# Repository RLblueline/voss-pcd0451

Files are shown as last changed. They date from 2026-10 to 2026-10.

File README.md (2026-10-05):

# V.O.S.S. — PCD-0451

**Virtual Oversight & Supervision System.** A wall-mounted, Claude-powered home assistant
on a spring-balanced robot arm, with a deep, late-'70s HR-terminal head:
- **Moves:** the arm swivels, lifts and leans, like a desk lamp.
- **Eye:** an amber eye slides up and down a slot behind mechanical eyelids.
- **Sound:** she answers out loud through an intercom filter.
- **Paper:** she prints memos.

> Personal, non-commercial fan build in the style of Valve's Portal. Aperture Science
> belongs to Valve; V.O.S.S. and Dr. Harriet Voss are original fan characters. The
> department seal is an original design, not the Aperture logo.

| | | |
|---|---|---|
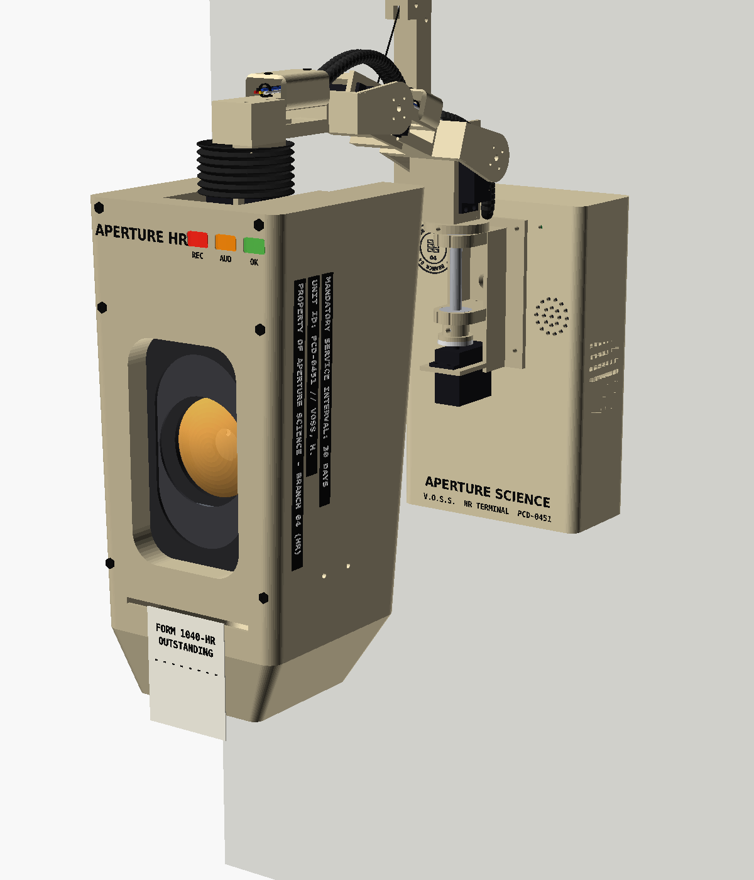
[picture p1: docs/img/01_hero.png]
Hero
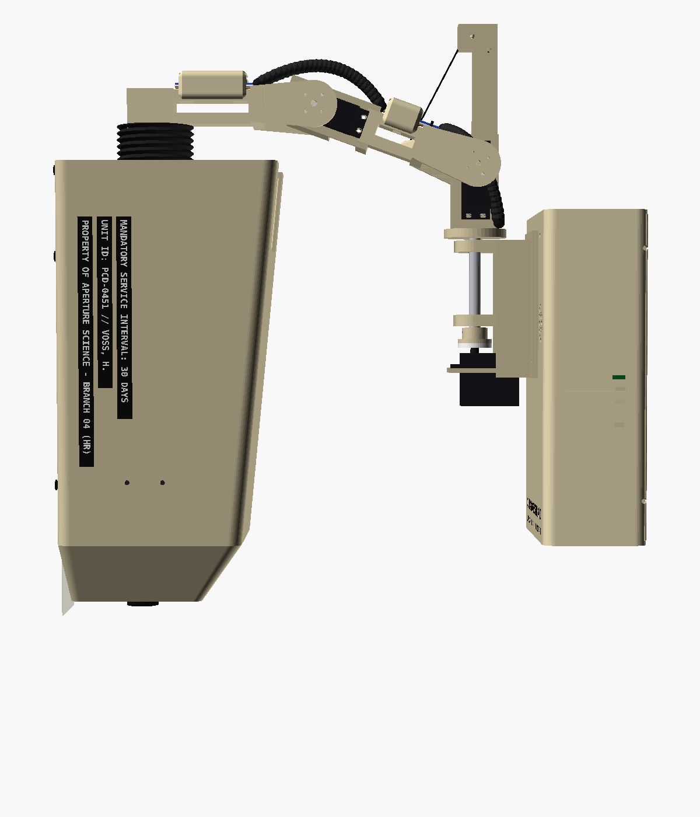
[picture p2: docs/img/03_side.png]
Side
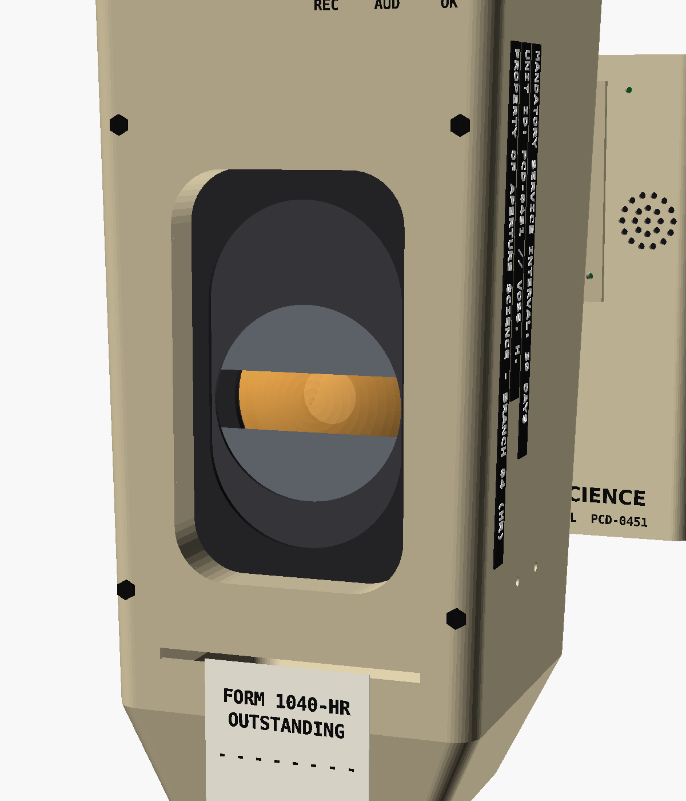
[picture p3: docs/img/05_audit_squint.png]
Audit squint
|  |  |  |
| Home pose on the wall | Arm and deep head, side view | Audit mode: eye low, lids squinted |

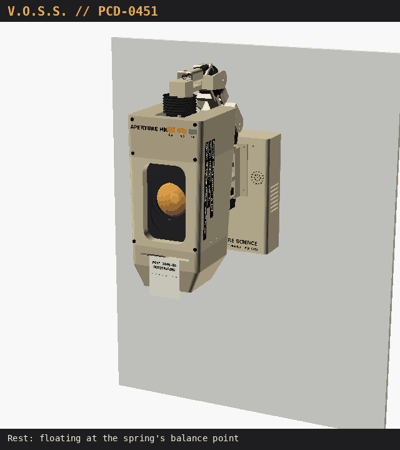
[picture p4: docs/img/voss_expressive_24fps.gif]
V.O.S.S. expressive routine


*Rendered from the CAD while the real firmware motion engine runs on a virtual clock: gestures, springy settles, blinks, speech bobs. Full quality: `docs/img/voss_expressive_24fps.mp4` (15 s, 24 fps, every frame rendered), slowed 1.5x: `docs/img/voss_expressive_24fps_slow.mp4` (22.5 s, 24 fps, motion-interpolated); longer 36 s cut: `docs/img/voss_expressive.mp4`.*

## Status (v0.7)

| Area | State |
|---|---|
| Software | Complete pipeline with an expression engine; 28 offline tests pass; **not yet run on hardware** |
| CAD | Full parametric OpenSCAD model. Collision sweep, gear-mesh, bolt-path and print-solid checks all pass |
| Build | **[`build/`](build/BUILD.md)**: 27 print-ready STLs, a JLC3DP order sheet, BOM (~$214 before printing), build guide |
| Hardware | Not built. Servo, printer and speaker dimensions are datasheet values to verify |

## What's in the repo

```
voss/            Python package (runs on the Pi as systemd service "voss")
tests/           Offline tests: VOSS_SIM=1 python -m unittest discover tests
deploy/          install.sh, systemd unit, config.txt lines, env template
build/           BUILD.md, BOM.csv, print_order_jlc3dp.csv, print_files/ (27 STLs)
cad/             OpenSCAD model, part export, renders, collision + load checks
  voss.scad        all parts, parametric
  assembly.scad    posed assembly (-D YAW= SH= EL= PITCH= EYE= SHUT=)
  view_eye.scad    eye carriage close-up
  tools/           parts.scad, export.sh, render.sh, collide.py, verify.py, loads.py,
                   head_mass.py, reach.py, animate.py, package_build.py
  stl/             every part, ready to slice
docs/            Build documentation
```

## Documentation

**Building one? Start with [build/BUILD.md](build/BUILD.md).**

0. [Personnel asset record (bio)](docs/00-bio.md)
1. [Overview and character](docs/01-overview.md)
2. [Hardware: BOM, wiring, power](docs/02-hardware.md)
3. [Mechanical design](docs/03-mechanical.md)
4. [Printing](docs/04-printing.md)
5. [Assembly](docs/05-assembly.md)
6. [Software](docs/06-software.md)
7. [Bring-up and calibration](docs/07-bringup.md)
8. [CAD workflow and gallery](docs/08-cad-workflow.md)

## Quick start (desktop, no hardware)

```bash
pip install -r requirements.txt
VOSS_SIM=1 python -m unittest discover tests
VOSS_SIM=1 VOSS_DATA=/tmp/voss ANTHROPIC_API_KEY=sk-ant-... python -m voss.main --text
```

## Key numbers

| | |
|---|---|
| Budget | ~$214 purchased parts (`build/BOM.csv`) + printing; Claude API billed separately |
| Arm | Yaw + shoulder + elbow + head tilt; L1 120, L2 100 mm; spring-balanced shoulder |
| Head | ~300 tall × 151 deep (crown) × 140 wide, ~690 g, kept level automatically; tilt −40…+50° |
| Eye | 60 mm amber lens on a carriage, ±24 mm travel in the slot, rack-and-pinion eyelids |
| Reach | head front up to ~430 mm off the wall, ~±255 mm side to side, ~315 mm up/down |
| Servos | MG996R yaw, 2× DS3225 shoulder + elbow, DS3218 tilt, 2× SG90 (eyelids, eye lift) |
| Brain | Pi Zero 2 W, local wake word + STT, Claude Haiku 4.5, Piper TTS |

See [CHANGELOG.md](CHANGELOG.md) for the history (M.E.M.O. v0.2 → V.O.S.S. v0.5).

## License

Software (`voss/`, `tests/`, `deploy/`, `cad/tools/`) is **MIT**. Hardware designs, print
files and docs (`cad/`, `build/`, `docs/`) are **CERN-OHL-S-2.0**: build it, change it, even
sell it, but share your modified design files under the same licence. See [LICENSE](LICENSE)
and [`LICENSES/`](LICENSES/).

Portal and Aperture Science belong to Valve. This is an unofficial, non-commercial fan project.

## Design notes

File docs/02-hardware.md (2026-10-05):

# 2. Hardware

## Bill of materials

Prices are rough, typical online prices (USD, late 2026).

| Qty | Part | Use | ~$ |
|---|---|---|---|
| 1 | Raspberry Pi Zero 2 W (with header) | brain | 15 |
| 1 | microSD 32 GB | | 7 |
| 2 | INMP441 I2S MEMS mic | 80 mm apart for direction of arrival | 6 |
| 1 | MAX98357A I2S amp + 40 mm 4 Ω 3 W speaker | voice | 8 |
| 1 | PCA9685 16-ch servo driver | OE wired to GPIO17 | 6 |
| 1 | MG996R | base yaw | 6 |
| 2 | DS3225 (25 kg·cm, standard size, 180°) | shoulder, elbow | 32 |
| 1 | DS3218 (20 kg·cm, 180°) | head tilt | 14 |
| 2 | SG90 | eyelids, eye lift | 6 |
| 1 | WS2812B 16-LED ring (44 mm OD) + 3 single WS2812B boards | eye, REC/AUD/OK | 9 |
| 1 | 58 mm TTL thermal printer + paper | memos | 25 |
| 1 | 5 V 5 A supply | Pi, amp, LEDs, printer | 12 |
| 1 | 6 V 6 A supply | servo rail | 15 |
| 2 | 608 bearings + 80 mm × 8 mm steel rod | yaw shaft | 5 |
| 3 | 624 bearings + M4 × 20 shoulder bolts | shoulder, elbow, tilt pivots | 4 |
| 2 | 3 mm steel rod, 150 mm | eye carriage guides | 2 |
| 1 | Extension spring ~2.1 N/mm, ~55 mm free length, OD ≤ 13 mm, ≥40 mm safe extension, ≥130 N; 1 mm braided cable + crimps | shoulder counterbalance (2:1) | 7 |
| — | Split-loom tubing (6–8 mm), zip ties, servo extension leads, 22–26 AWG wire | harness and service tubes | 8 |
| — | M3 screws + heat-set inserts, M4 nylocs | | 6 |
| — | 1000 µF cap, 330 Ω resistor, 2 DC jacks | | 3 |
| — | Filament: ~1.3 kg beige PLA/PETG, charcoal, grey, TPU, translucent amber | plan 1.5–2 kg with reprints | 30–40 |
| (opt) | 74AHCT125 level shifter | only if LEDs glitch | 2 |

**Total: about $214 for purchased parts (see `build/BOM.csv`), plus printing.** Printing
at home costs about $30–40 in filament. A print service costs noticeably more; get a quote
from the order sheet.

Where the money goes compared with the classic arm (v0.4):
- The **desk-lamp spring** saves about $5–8. The DS3225s replace the 35 kg·cm servo, and
  a 6 A supply replaces the 10 A one.
- The new **eye lift** (SG90), the **harness and tubes**, and the bigger head's filament
  add about $15–20.

Cost levers:
- the printer (about $25)
- one 6 V supply plus a 5 V buck converter
- servo multi-packs
- 1.6 mm head walls (less filament, lighter head)

## Wiring

| Signal | Pi Zero 2 W pin | Goes to |
|---|---|---|
| I2S BCLK | GPIO18 | both INMP441 SCK, MAX98357A BCLK |
| I2S LRCLK | GPIO19 | both INMP441 WS, MAX98357A LRC |
| Mic data | GPIO20 | both INMP441 SD |
| Amp data | GPIO21 | MAX98357A DIN |
| I2C SDA / SCL | GPIO2 / GPIO3 | PCA9685 |
| Servo output enable | GPIO17 | PCA9685 OE (active low) |
| LED data | GPIO10 (SPI0 MOSI) | 330 Ω → eye ring DIN → REC → AUD → OK |
| Printer | GPIO14 (UART TX) | printer RX |

- **Mics:** left mic L/R → GND (channel 0, at −X); right mic L/R → 3.3 V (channel 1, at +X).
- **Don't use GPIO16:** the voicehat overlay claims it.
- **PCA9685 channels:** 0 yaw, 1 shoulder, 2 elbow, 3 tilt, 4 eyelids, 5 eye lift.

### Harness

One bundle runs from the housing up through the yaw tower's cable hole, then:
1. through a corrugated service loop to the turret
2. along the top of link1 under its cover
3. over the elbow in a second service loop
4. along the top of link2 under its cover
5. down into the open back of the head through two neck tubes

It carries:
- 4 servo leads: elbow, tilt, eyelids, eye lift (the yaw and shoulder servos sit at the base)
- the LED data/5 V/GND line for the eye ring and status bar

Leave about 30 mm of slack at each loop for the full joint range.

## Power

```
5 V 5 A ──┬── Pi Zero 2 W (5 V pins)
          ├── MAX98357A VIN
          ├── WS2812 chain (19 LEDs)
          └── thermal printer
6 V 6 A ──┬── PCA9685 V+ (servo rail) ── 1000 µF across V+/GND
          └── (nothing else)
GND ─────── common to both supplies, the Pi and the PCA9685
```

- **Holding current:** the counterbalance spring keeps steady holding current low. The
  6 A supply covers several servos moving at once with margin.
- **Printing:** the firmware never prints while the arm moves. The joints keep holding;
  the separate rail means the printer can't brown them out.
- **Shutdown:** the arm parks at the spring's balance point before OE cuts power, so it
  barely drifts.

## Free pins

GPIO 4, 5, 6, 12, 13 and 22–27 are free, which is handy for a button or a Home Assistant
status LED.

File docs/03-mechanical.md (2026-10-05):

# 3. Mechanical design

All dimensions in mm. The model is `cad/voss.scad`; every number below is a named
parameter at the top of that file.

## Frame

X along the wall, Y out of the wall, Z up. Wall face is y = 0. The yaw axis is vertical at
**(0, 112)**. The shoulder pitch axis crosses it **70 mm above the housing origin**
(`ARM_Z0`), which keeps the arm and the spring mast above the housing top at every yaw. The firmware uses the same frame
(`voss/config.py`).

Side view

## Joints

| Joint | Axis | Servo | Range (checked) | Zero |
|---|---|---|---|---|
| Yaw (base) | vertical, (0, 112) | MG996R | 5–175° | 90 = straight out from the wall |
| Shoulder | horizontal, on the yaw axis at z 0 | DS3225 + counterbalance spring | −20…+75° | 0 = link1 level, + lifts |
| Elbow | horizontal, 120 mm along link1 | DS3225 | −110…+40° | 0 = links in line |
| Head tilt | horizontal, 14 mm past link2 and 72 mm below it | DS3218 | **−40…+50°** relative to link2 | 0 = head in line with link2 |
| Eyelids | involute rack and pinion (module 1, 18 T) on the eye carriage | SG90 | 0–1 | 1 = open |
| Eye lift | involute rack and pinion (module 1, 36 T), carriage on two rods | SG90 | ±24 mm (−1…1) | 0 = centred |

**Head pitch.** The firmware commands absolute head pitch and derives
`tilt = pitch + shoulder + elbow`. Lifting the arm keeps the head level unless she means
otherwise. The shoulder does most of the raising and lowering: the head's height range is
about 155 mm, and the infraction stamp drops it about 80 mm.

| Raised (rest / balance point) | Stamp (dropped) |
|---|---|
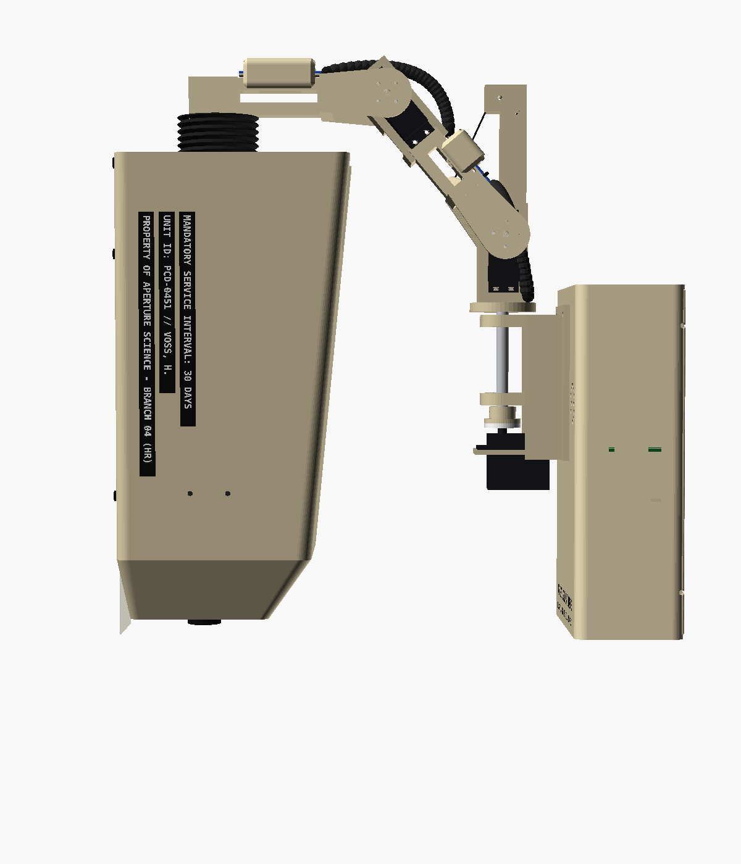
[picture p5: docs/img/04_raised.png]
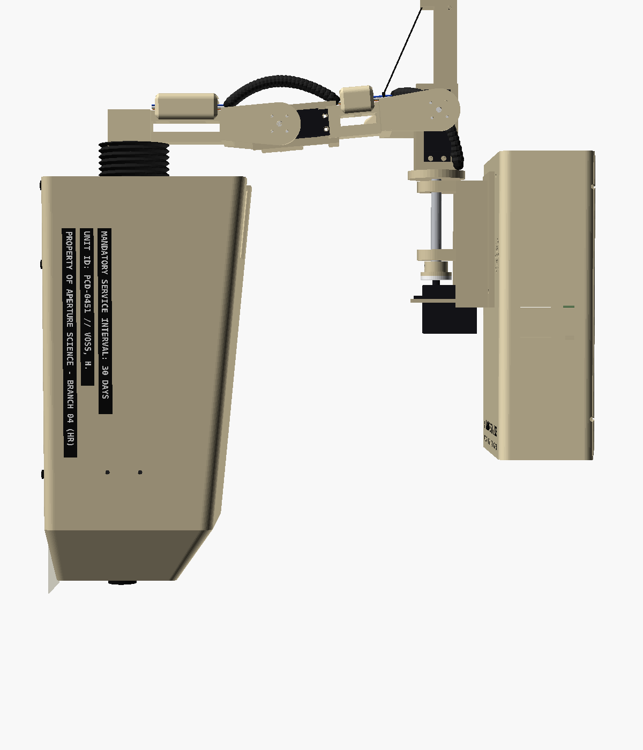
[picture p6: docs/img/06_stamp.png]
|  |  |

| Deep nod (+45°) | Looking up (−40°, eye high) |
|---|---|
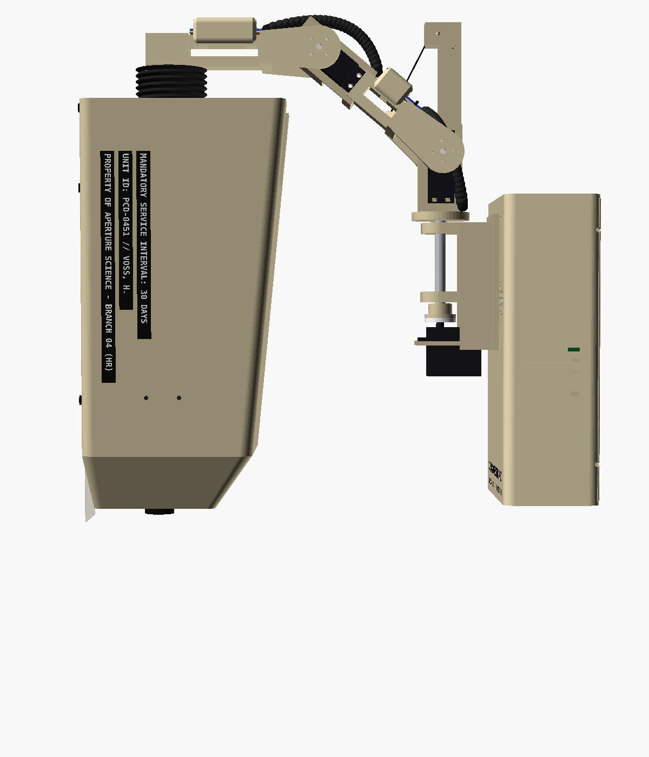
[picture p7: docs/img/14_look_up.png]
|  |  |

## How the arm is built

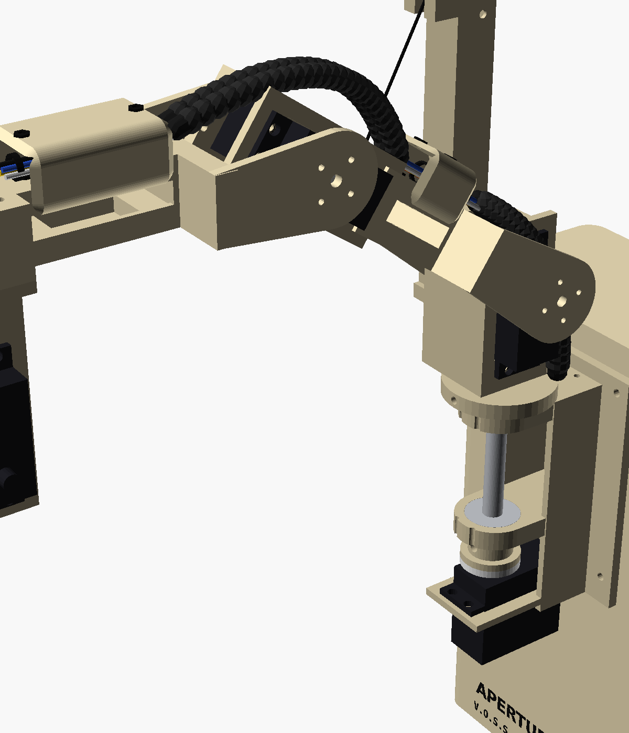
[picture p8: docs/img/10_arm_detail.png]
Arm detail


- **Joint brackets.** Every pitch joint uses the same bracket:
  - the servo mounts through a flange plate
  - a pivot plate holds a 624 bearing coaxial with the shaft on the far side
  - two side bars tie the plates together
- **Links.** The next link wraps each bracket with two side plates. One sits on the horn;
  the other rides an M4 shoulder bolt in the 624. At 36–44 mm from the axis, a cross block
  joins the plates to a hollow 20 × 24 mm centre beam.

| Assembly | What it is |
|---|---|
| Yaw tower (world) | Bolted to the housing front. An 8 mm shaft runs in two 608 bearings 52 mm apart, which carry the arm's moment. The MG996R below drives the shaft through a horn coupler |
| Turret (yaw frame) | Clamped to the top of the shaft. Joint bracket with the shoulder servo body down, plus the **gooseneck spring mast** |
| Link1 | Side plates around the turret, centre beam with a top cover, and the elbow joint bracket. Has the counterbalance cable eye |
| Link2 | Side plates around the elbow bracket, centre beam with a top cover, end block carrying the tilt post |
| Tilt post | Joint bracket with the DS3218 body pointing up. The neck narrows above the flange to clear the crown |

### Desk-lamp counterbalance

The trick from Anglepoise lamps: a spring whose force is proportional to its stretched
length exactly cancels a link's weight at every angle, if two conditions hold:
- one end sits directly above the pivot
- the other end sits on the link's axis line

| Element | Detail |
|---|---|
| Top pulley | 10 mm, M3 axle, **96 mm above the shoulder axis** on the turret's mast |
| Cable eye | On link1's axis line, 50 mm out, in the plane y = −42 (outside the link) |
| Coplanar path | The cable, top pulley and spring all lie in one vertical plane, so the cable can't jump the pulley |
| **2:1 reeving** | The cable runs from the eye, over the top pulley, down under a 7 mm pulley on a spring block, and back up to an anchor pin. The spring sees half the travel at twice the force |
| Spring | About 2.1 N/mm, about 55 mm free length, 37 mm travel (about 65%, well within a normal extension spring's life), up to ~127 N |
| Tuning | The tensioner screw at the bottom of the mast sets the cable-length offset, which turns a normal spring into an "ideal zero-length" spring |

## Loads

From `cad/tools/loads.py`. Masses come from the CAD volumes: head about 690 g, centre of
gravity 1 mm from the tilt axis. Values are static, in kg·cm, with link2 level.

| Shoulder angle | Shoulder (gravity) | Shoulder (with spring) | Elbow |
|---|---|---|---|
| −20° | 19.4 | −4.5 | 9.2 |
| 0° | 20.0 | −5.4 | 9.2 |
| 20° (home) | 19.3 | −4.5 | 9.2 |
| 45° | 16.8 | −1.1 | 9.2 |
| 60° | 14.6 | +1.9 | 9.2 |
| 75° | 12.0 | +5.4 | 9.2 |

- **Shoulder.** The DS3225 works at no more than about 22% of its rating. If the spring
  ever fails it can still hold the arm (about 80%), but don't run it that way.
- **Unpowered.** The arm floats to about **51°** and stays there.
- **Elbow.** The DS3225 runs at about 37%.
- **Tilt.** The head is a balanced pendulum, so tilt needs at most about 6 kg·cm at
  ±45°. The DS3218 runs at about 30%.

## Head

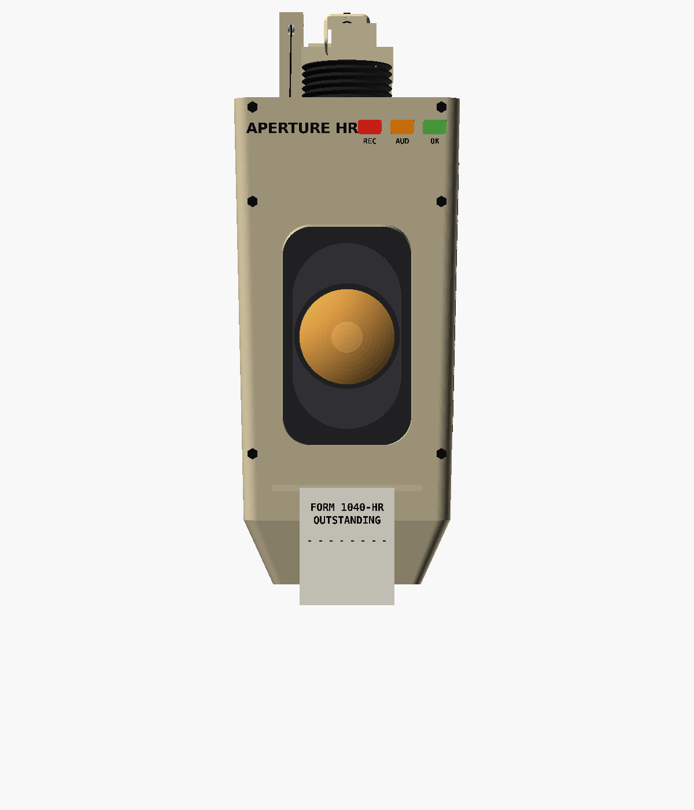
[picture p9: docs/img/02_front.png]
Front


**Envelope (shell frame):**
- flat front at x 45
- back at x −105 at the crown and x −80 at z −230, so the top half stretches back further
- the chin tapers to 90 × 92 at z −270
- 140 wide at the crown

**Mounting:**
- The shell is shifted 15 mm (`HS`) relative to the tilt axis, so the deeper head's
  centre of gravity hangs under the axis.
- **Shell:** 2.4 mm walls in three pieces split at z −40 and −195, with skirts, M3 bosses
  and black hex screws.
- **Open back:** the neck slot runs from the crown down to 28 mm below the tilt axis and
  through the whole upper back. It widens to ±35 behind the ears, so link2's cross block
  can dip into it on deep nods. That gives the 90° tilt range, and it's where the service
  tubes enter.

### Moving eye

| Eye up, lids open | Eye down, lids closed |
|---|---|
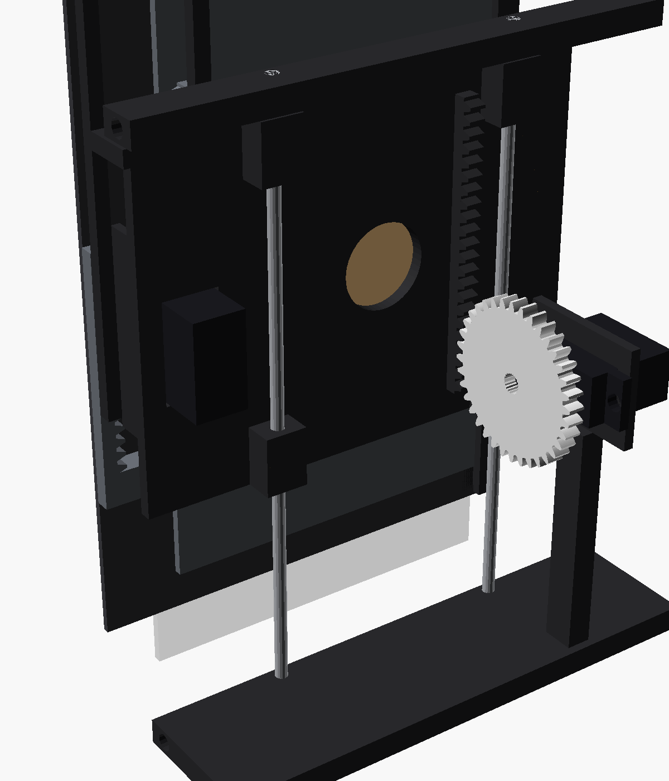
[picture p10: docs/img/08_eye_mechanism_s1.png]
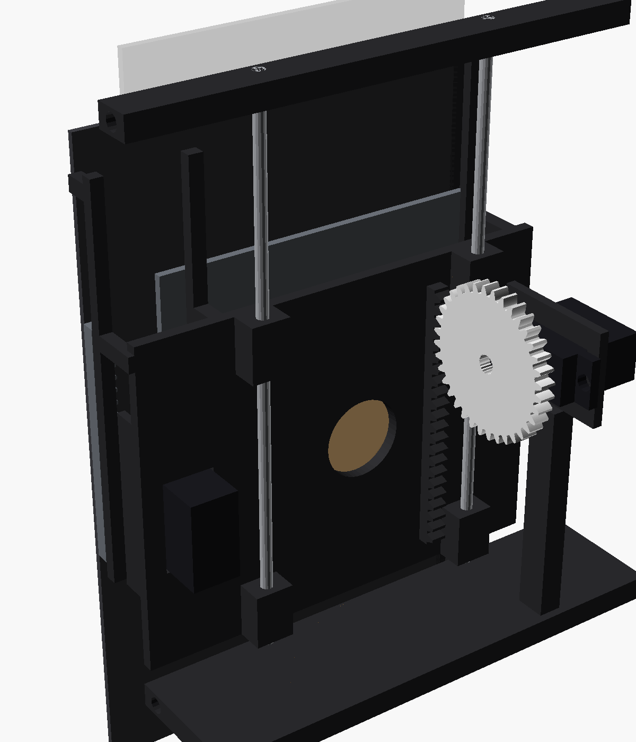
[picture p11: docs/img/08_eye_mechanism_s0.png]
|  |  |

**Fixed parts:**
- **Slotted plate:** the recess back, x 27–29. It has a 68 mm wide stadium slot covering
  the eye's ±24 mm travel.
- **Guide rods:** two 3 mm steel rods at y ±30, mounted on top and bottom bars.
- **Lift drive:** an SG90 on a strut drives a 36-tooth pinion (r 18) against a rack on the
  carriage's back. ±80° of servo gives ±24 mm.

**Carriage** (moves as one, about 70 g, so the lift servo barely notices it):

| x (shell frame) | Part |
|---|---|
| 25–26.6 | **Mask** (eye socket) with a Ø66 window. 166 tall, so it always covers the slot and hides the open eyelids |
| 22.6–24.6 | Eyelid plates (84 × 40) |
| 18.8–22.4 | Racks + eyelid pinion (r 9) |
| 15.4–18.6 | Rack backing rails |
| 13–21 | Ø60 amber lens |
| 8–12 | 16-LED ring |
| 3–6 | Rear plate |
| −4…3 | Rod bushings and lift rack |

**Eyelids.** Each plate travels 27 mm in opposite directions (about 172° of SG90 rotation).
Closed, they leave a 12 mm slit.

## Arm covers and harness

- **Covers.** Top-only shrouds snap onto the link beams with two clip screws each.
  - link1: x 46–74, stopping short of the elbow bracket
  - link2: x 46–96, stopping short of the tilt post
  - Each is 30 wide, open underneath, with 2 mm walls.
- **Harness.** The wire bundle and its zip ties sit on top of the beam under the cover.
  Between covers, the harness runs through corrugated service tubes with slack for each joint:
  - housing → turret
  - over the elbow
  - link2 → head

## Housing and tower

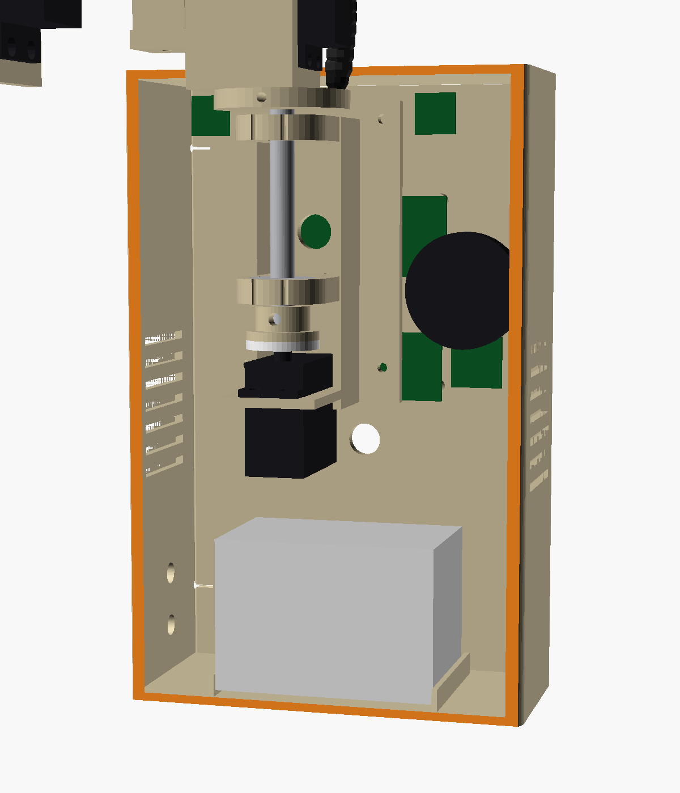
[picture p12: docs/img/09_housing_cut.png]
Housing interior


- **Housing:** 144 × 70 × 226.
- **Front:** mics 80 mm apart, speaker grille on the left, the department seal on the
  right, lettering along the bottom.
- **Underside:** the printer is mounted exit-down, so memos drop out of a slot in the
  bottom face with a tear bar.
- **Sides:** DC jacks and vents.
- **Wall:** the back plate has keyholes for one stud.

## Collision check results

`cad/tools/collide.py` sweeps:
- **yaw:** 5° steps with the arm at home
- **shoulder:** 5° steps with link2 level
- **elbow:** 5° steps with the head
- **tilt:** −40…+50° with the eye at both ends of its travel and the lids open and closed
- **eye and eyelids:** heights −1/0/1 × lids 0/0.5/1 against everything in the head

It then tests a 4-D grid of yaw, shoulder, elbow and head pitch. Every pose the firmware
accepts is checked for head, links and covers against the housing, tower, wall and the
arm itself.

```
yaw 5..175 : turret/link1 vs housing/tower         OK
gear meshes : pinions vs racks (no interference)   OK
gear meshes : half-tooth turn jams (engaged)       OK
shoulder -20..75 : link1/link2 vs turret/tower     OK
elbow -110..40 : link2/head vs link1/turret        OK
tilt -40..50 : head vs link2/post                  OK
eye -1..1, shutters 0..1 : vs head internals       OK
firmware workspace: 429 poses accepted, 1881 rejected
accepted poses : arm/head vs housing, tower, wall, arm OK
```

**Gears** are real involute profiles (module 1, 20°, ~0.1 mm backlash), phased so a tooth
faces each rack's gap at the zero position. The checker confirms there's no interference
over the full travel, and that a half-tooth turn jams, which proves the teeth engage.

## Fastening (all checked by `cad/tools/verify.py`)

| Joint | Fasteners |
|---|---|
| Tower → housing | 4 × M3 + nuts; 12 mm harness hole aligned |
| Housing → back plate | 4 × M3 into edge inserts |
| Tilt post → link2 | 2 × M3 self-tapping |
| Arm covers → beams | 2 × M3 each into inserts in solid beam pads |
| Head seams | 4 × M3 × 16 per seam, up from inside into inserts in the piece above |
| Eye rod bars → head walls | 6 × M3 through the side walls into bar-end inserts |
| Yaw coupler → shaft | M3 set screw in an insert |
| Pinions → SG90s | Splined bore (21 T press fit) plus the M2 horn screw |

The front "hex screws" on the head are decorative.

## Known risks

1. **Spring tuning.** The balance is only as good as the spring (2.1 N/mm, 2:1 reeved). Use `voss.calibrate float`
   and the tensioner screw (see [Bring-up](07-bringup.md)).
2. **Unverified dimensions.** Servo, printer and speaker dimensions are datasheet values,
   and the DS3225s are modelled at DS3218 size. Measure yours.
3. **Head weight.** About 690 g with 2.4 mm walls. 1.6 mm walls bring it nearer 520 g and
   ease every joint; re-run `loads.py` and re-fit the spring.
4. **Eye lift backlash.** A loose lift pinion lets the eye drop a little when the servo
   is released. The firmware keeps the eye servo powered.
5. **Projection.** At home the head front sits about 400 mm off the wall. Mount it away
   from walkways.
6. **Print bed.** The housing needs a bed of at least 230 mm in one axis; the head crown
   is 151 × 140.

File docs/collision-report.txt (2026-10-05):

yaw 5..175 : turret/link1 vs housing/tower         OK
shoulder -20..75 : link1/link2 vs turret/tower     OK
elbow -110..40 : link2/head vs link1/turret        OK
tilt -40..50 : head vs link2/post                  OK
eye -1..1, shutters 0..1 : vs head internals       OK
gear meshes : pinions vs racks (no interference)   OK
gear meshes : half-tooth turn jams (engaged)       OK  (min 15.9 mm^3)
firmware workspace: 473 poses accepted, 1837 rejected (yaw/shoulder/elbow/pitch grid)
accepted poses : arm/head vs housing, tower, wall, arm OK

ALL CLEAR

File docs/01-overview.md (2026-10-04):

# 1. Overview and character

## Lore

V.O.S.S., unit **PCD-0451**, is an archived Aperture Science HR-compliance AI from
branch `hr-compliance`. She was built from the uploaded mind of **Dr. Harriet Voss**,
Director of Personnel Compliance, who traded the upload for a reserved parking space she
never got to use. The product line was named after her; nobody asked.

Reactivated as a wall terminal on an articulated arm, she treats the person in the room
as the facility's last remaining employee and calls them **"Employee"**.

## Behaviour rules

- Bureaucratic humour: memos, write-ups, the permanent record, mandatory fun, upbeat
  corporate cheer.
- Always genuinely helpful first; the bit is seasoning.
- Short spoken replies (one to three sentences).
- **Drops the act** when Employee is genuinely upset, scared or unwell: plain, warm,
  brief, no jokes. In an emergency she tells them to contact emergency services.
- Only writes to the permanent record or prints when asked.

## How she moves

The arm is spring-balanced like a desk lamp, so the servos mostly steer rather than lift.
Motion uses minimum-jerk easing, which gives slow, fluid, GLaDOS-like sweeps instead of
robotic snaps.

While she's awake and idle, she "breathes":
- the arm drifts a few degrees on slow, unrelated rhythms
- the eye makes small flicks up and down the slot

While she talks, the head lifts slightly on stressed syllables.

## Expression

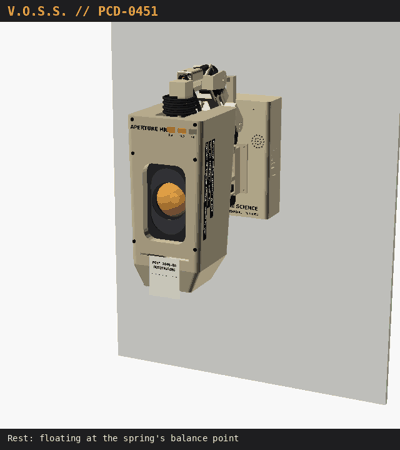
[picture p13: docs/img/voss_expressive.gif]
Expressive routine


She moves like an animated character:
- **Anticipation:** she dips before she rises.
- **Overshoot:** looks and nods overshoot and settle.
- **Blinks:** her eyelids blink.
- **Moods:** her mood changes how she idles.
- **Gestures:** Claude can add a gesture to any reply: nod, shake, peer, double take, startle, sigh, scan or curious.

See [Software → Expression engine](06-software.md#expression-engine).

## Moods

Every Claude reply starts with a mood tag. The tag drives pose, eye, eyelids and lights.

| Tag | When | Body | Eye | Lights |
|---|---|---|---|---|
| `[approve]` | praise, task done | nod | lifts slightly | amber, **OK** lamp on |
| `[neutral]` | normal answers | head level | centred | amber follows speech |
| `[infraction]` | playful scolding | **looms**: rises and squints, then drops about 80 mm with a nose-down snap and a THUNK | drops low ("over the glasses") | amber flicker |
| `[concern]` | genuinely upset | comes down lower and closer, slow and still | centred, lids locked open | dim tungsten |
| `[sulk]` | mock offence | swings away, head drooped | downcast | dim; returns after 6 s |

Other states:

| State | Behaviour |
|---|---|
| Listening | Swings toward the talker (direction of arrival) with a small overshoot and settles, leaning in. Eye lifts a little; REC brightens |
| Thinking | Rises and tips forward, eye rolls up, light sweeps the eye ring, AUD pulses |
| Filing | Eyelid flutter plus a relay click when she saves a note |
| Rest | After 45 s idle, she settles at the spring's balance point with the head level. Yaw, tilt and eyelid servos go limp and silent |

| Eye up | Eye down |
|---|---|
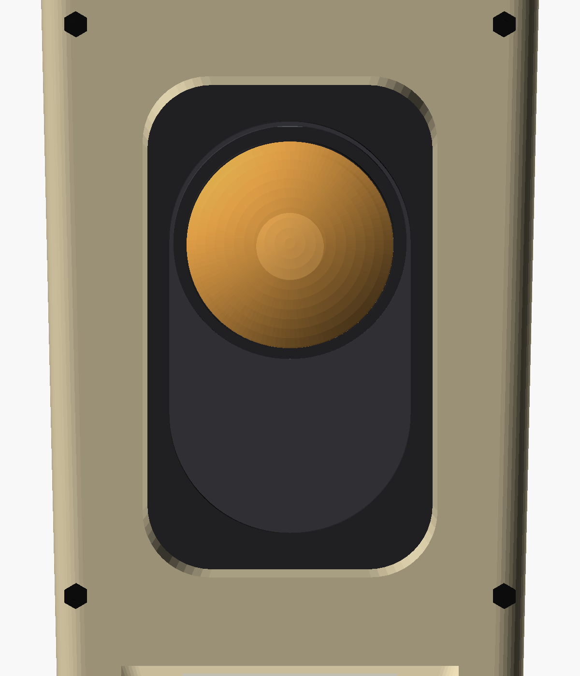
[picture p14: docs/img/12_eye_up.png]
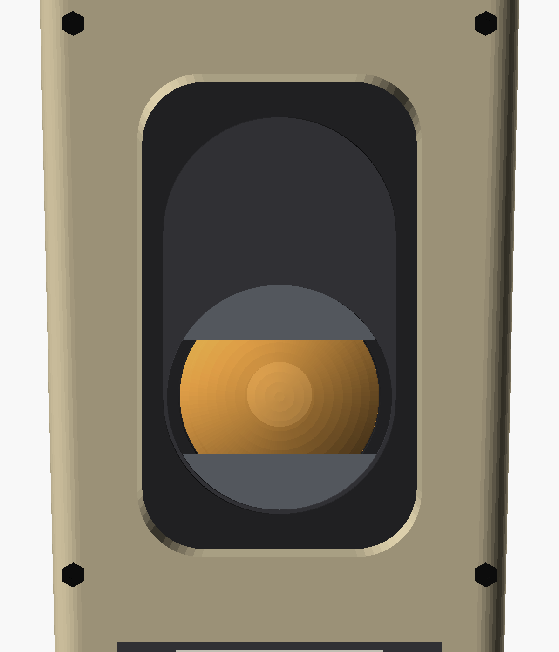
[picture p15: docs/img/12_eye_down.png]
|  |  |

## The head

The head is an oversized punch-card reader crossed with a microfiche machine and an '80s
desk PC.

- **Silhouette:**
  - A deep corporate-beige wedge with a flat front.
  - It stretches back 151 mm at the crown and 125 mm lower down, and the chin tapers.
  - The upper back is open around the neck, so the head can tilt through 90°.
  - It's split into three panels with visible black hex screws.
- **Upper status housing:** "APERTURE HR" lettering and three backlit blocks:
  - **REC** (red) is always on.
  - **AUD** (amber) pulses while she processes.
  - **OK** (green) lights on approval.
- **Eye:** a tall charcoal recess. Behind its slotted back plate, a 60 mm amber lens with a
  16-LED ring rides up and down. Two grey eyelid plates ride with it:
  - **Open:** neutral and cheerful.
  - **12 mm slit:** audit.
  - **Flutter:** filing.
  - **Locked open:** empathy.
- **Chin:** a fake printer slot with a hanging "FORM 1040-HR: OUTSTANDING" strip and a
  black bumper underneath. The real printer drops memos out of the bottom of the wall housing.
- **Sides:**
  - **Right:** three Dymo labels (PROPERTY OF APERTURE SCIENCE - BRANCH 04 (HR);
    UNIT ID: PCD-0451 // VOSS, H.; MANDATORY SERVICE INTERVAL: 30 DAYS).
  - **Left:** the department seal: an original "PERSONNEL COMPLIANCE • BRANCH 04" ring
    around a filing-drawer emblem.
- **Neck:** a black bellows boot, with corrugated service tubes looping into the open back.

### Design-brief items that were adapted

| Brief | Built as | Why |
|---|---|---|
| 20 × 8 in head | ~12 in tall, 6 in deep, 5.5 in wide | Torque, stiffness, budget |
| Ball-and-socket gimbal | Single tilt axis plus a cosmetic bellows boot | One servo; the arm supplies the rest |
| Sideways "over-the-shoulder" lean | Yaw swing plus head pitch | A roll axis would need another servo |
| Pneumatic 2 in "stamp" drop | **Real** ~80 mm loom-and-drop of the whole head | — |
| Matrix printer in the chin | Cosmetic slot; the real printer is in the housing | Weight and wiring |
| Aperture logo | Original Branch 04 seal | The real logo is Valve's artwork |

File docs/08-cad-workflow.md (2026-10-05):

# 8. CAD workflow

Tools:
- OpenSCAD 2021.01 or newer
- `pip install trimesh manifold3d numpy` for the checkers
- `xvfb-run` for headless renders

## Files

| File | Purpose |
|---|---|
| `cad/voss.scad` | Every part as a module in its own local frame; all parameters at the top |
| `cad/assembly.scad` | Posed assembly: `-D YAW= SH= EL= PITCH= EYE= SHUT=` plus `SHOW_WALL`, `SHOW_HOUSING`, `SHOW_HEAD`, `SHOW_SHELL`, `CUTAWAY` |
| `cad/view_eye.scad` | Eye carriage close-up (`-D EYE= SHUT=`) |
| `cad/tools/parts.scad` | Exports one part: `-D 'PART="link1"'` (eye parts take `-D PE=` for height) |
| `cad/tools/export.sh` | Exports every part to `cad/stl/` (eye at −1/0/1, eyelids at 0/0.5/1) |
| `cad/tools/render.sh` | Renders every view in these docs to `docs/img/` |
| `cad/tools/collide.py` | Joint sweeps, moving-eye checks and the firmware-pose grid |
| `cad/tools/loads.py` | Static joint torques and the best counterbalance spring |
| `cad/tools/head_mass.py` | Head mass and centre of gravity (for choosing `HS`) |
| `cad/tools/reach.py` | Reach envelope over firmware-accepted poses |
| `cad/tools/verify.py` | Build checks: every bolt path clear through both parts, every print file a single watertight solid |
| `cad/tools/package_build.py` | Writes `build/` (print files, JLC3DP order sheet, BOM) |
| `cad/tools/animate.py`, `compose_anim.py` | Renders the expressive routine (15 s at 24 fps, 361 frames): the firmware `Body` runs on a virtual clock and every frame is a sample of its output, checked by the workspace check. Uses `FAST=true` (heavy parts load their exported STLs) for ~4.5 s/frame. `python3 cad/tools/animate.py [N]` renders N more frames; then compose |

## Frames and transforms

| Group | Frame | Transform from its parent |
|---|---|---|
| Housing, back plate, yaw tower, yaw servo | world | — |
| Turret + spring mast, shoulder servo, yaw coupler | turret | `translate([0, SY, ARM_Z0]) rotate([0, 0, YAW])` |
| link1 (incl. elbow bracket), cover, elbow servo | link1 | `rotate([0, -SH, 0])` |
| link2, cover, tilt post, tilt servo | link2 | `translate([L1, 0, 0]) rotate([0, -EL, 0])` |
| Head (tilt-axis frame) | head | `translate([L2 + TILT_OFF, 0, -TILT_DROP]) rotate([0, TILT, 0])` |
| Head shell and eye (shell frame) | shell | `head_frame()` = `translate([HS, 0, 0])` inside the head frame |

In `assembly.scad`, `HEAD_LEVEL=true` (the default) sets `TILT = SH + EL + PITCH`.
`collide.py` uses the same transforms; change both together.

## Typical edit loop

```bash
cd cad
nano voss.scad                       # e.g. new servo dimensions or a thinner head shell
./tools/export.sh                    # ~2-3 min
python3 tools/head_mass.py           # head CG x should be ~0; adjust HS if not
python3 tools/loads.py               # torques + spring rate
python3 tools/collide.py             # must end with ALL CLEAR
python3 tools/verify.py              # must end with ALL CHECKS PASSED
python3 tools/package_build.py       # refresh build/
./tools/render.sh                    # refresh docs/img
```

If arm or head geometry changes, update `voss/config.py` (`YAW_XY`, `L1`, `L2`,
`TILT_OFF`, `TILT_DROP`, `HEAD_SECTIONS`, `OBSTACLES`, `LIMITS`) so the firmware's
workspace check still matches.

## Gallery

| | | |
|---|---|---|
|  |  |  |
| Hero | Front | Side (home) |
|  |  |  |
| Raised (balance point) | Audit squint | Stamp (dropped) |
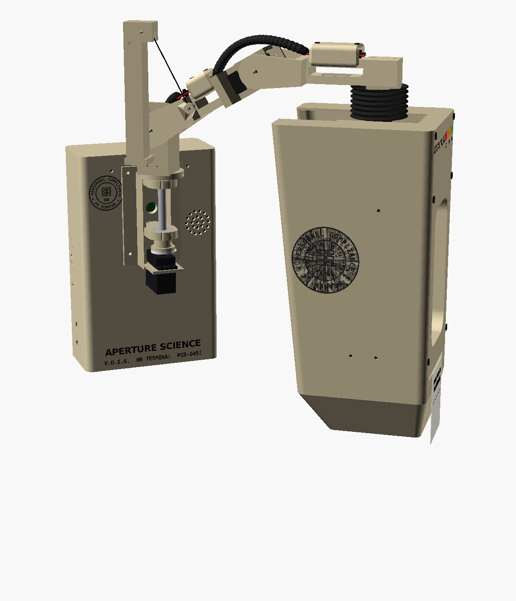
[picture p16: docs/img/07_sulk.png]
|  |  |  |
| Eye up | Eye down, lids half shut | Sulk (department seal on the left side) |
|  |  |  |
| Deep nod (+45°) | Looking up (−40°) | Turret, spring mast, covers, harness |
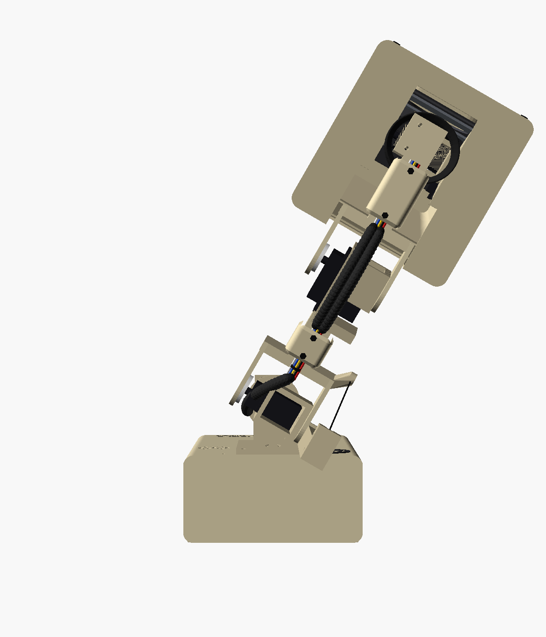
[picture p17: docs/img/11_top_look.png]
|  |  |  |
| Eye carriage, up and open | Eye carriage, down and closed | Plan, looking at a talker |

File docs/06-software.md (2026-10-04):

# 6. Software

Python 3, installed to `/opt/voss` and run as the systemd service `voss`.

## Pipeline

```
arecord (I2S stereo, 16 kHz) ──► openWakeWord ──► GCC-PHAT DOA ──► arm swings to the talker
                                                        │
                    webrtcvad endpointing + Vosk small-en (streaming, local)
                                                        │
             Claude (claude-haiku-4-5-20251001) ◄──► tools (timers, weather, notes, print…)
                                                        │
                    "[mood] reply"  ──►  pose + eye + eyelids + lights
                                                        │
           Piper en_US-amy-low ──► sox intercom filter + chime/sfx ──► aplay
                                   (speech envelope drives the eye light and a head bob)
```

- **Local stages:** the wake word and speech-to-text run on the Pi. Only the transcript goes to Claude.
- **Conversation memory:** the last 8 exchanges are kept as plain text.
- **Tool loop:** up to 5 tool rounds per reply.
- **Failure:** if Claude can't be reached, she says an in-character fallback line.

## Modules (`voss/`)

| Module | Role |
|---|---|
| `config` | Every setting, overridable with `VOSS_*` environment variables |
| `persona` | System prompt (lore and rules) and mood-tag parsing |
| `audio` | Capture thread (48→16 kHz decimator), playback with level envelope, GCC-PHAT direction of arrival |
| `stt` | Wake word and utterance capture with Vosk |
| `tts` | Piper → sox intercom chain → chime / thunk / relay-click sfx |
| `lights` | WS2812 over SPI (eye ring, REC, AUD, OK) at 50 Hz |
| `body` | PCA9685 driver, calibration, kinematics, workspace check, segment-based motion engine, alive overlay |
| `gestures` | Expression library: easing styles, gestures, mood entries and idle profiles (data, easy to tune) |
| `printer` | ESC/POS layouts: memo, write-up, commendation, checklist |
| `tools` | Claude tool schemas and handlers |
| `brain` | Claude tool-use loop and rolling history |
| `main` | Orchestration (voice mode, or `--text` keyboard mode) |
| `calibrate` | Bring-up command-line tool |

## Tools available to Claude

| Tool | What it does |
|---|---|
| `get_time` | Local date and time |
| `set_timer` / `list_timers` / `cancel_timer` | Countdown timers, announced aloud when they finish |
| `get_weather` | Open-Meteo (no key) for home or a named place |
| `checklist` | "Mandatory Preparedness Checklist" to-do list |
| `notes` | "Permanent record" notes: add, list, search, delete |
| `print_memo` | Print a memo, write-up, commendation or the checklist |

## Motion model

**Pose joints:** `yaw`, `shoulder`, `elbow`, `pitch` (absolute head pitch, + nose down),
`shutter` (eyelids 0–1) and `eye` (height in the slot, −1…1).

**Servo channels:** yaw, shoulder, elbow, tilt, shutter, eye. The tilt servo is derived
as `tilt = pitch + shoulder + elbow`; if that would leave −40…+50°, pitch is adjusted to fit.

| Pose | yaw | shoulder | elbow | pitch | eye | Notes |
|---|---|---|---|---|---|---|
| Home | 90 | 20 | −20 | 0 | 0 | |
| Listen / look | 90 − DOA | 12 | −8 | −4 | 0.2 | eye leads, springy settle |
| Think | — | 30 | −34 | 8 | 0.6 | eye rolls up |
| Stamp | — | 35 → −5 | −35 → 5 | 10 → 15 | −0.4 | loom, then ~80 mm drop at 4× speed |
| Concern | — | 8 | −10 | −3 | 0 | slow |
| Sulk | 145 | 30 | −30 | 15 | −0.6 | |
| Rest / park | 90 | 50 | −50 | 0 | 0 | spring balance point |

### Expression engine

All motion is a queue of timed segments, each with its own easing style:

| Style | Feel | Used for |
|---|---|---|
| `ease` | Minimum-jerk, smooth start and stop | ordinary moves |
| `spring` | ~12% overshoot, then settles | looks, nods, recoveries |
| `snap` | Fast start, gentle stop | startles, double takes, the stamp drop |
| `slow` | Symmetric, sigh-like | peering, sighing, concern |
| `hold` | Stays put (idle sway and blinks continue) | dramatic pauses |

**Gestures** live in `voss/gestures.py` as data. Each step either moves to absolute joints
or offsets from the gesture's anchor, with a duration, style and hold. Every step and every
spring overshoot passes the workspace check, otherwise it's held or softened, so a gesture
can never drive her into the wall.

| Gesture | What she does |
|---|---|
| `nod` / `ack` | Snap down, slight overshoot back up |
| `bounce_nod` | Small dip (anticipation), pop up, nod, settle (her approve) |
| `shake` | Damped no |
| `peer` | Tiny lift, then a slow lean in, low, eye down, lids narrowed |
| `double_take` | Glance away, hold, snap back with the eye up |
| `startle` | Recoil up and back, eye wide, slow recovery |
| `sigh` | Slow sink with heavy lids, slow rise |
| `scan` | Look around the room with eye flicks |
| `curious` | Springy head lift and slight turn, eye up |
| `stamp` | Dip, loom and squint, hold, ~80 mm drop, springy settle (her infraction) |
| `glance_back` | During a sulk: stays turned away, then a quick resentful look back |
| `flutter` | Eyelid flutter while filing a note |

**Claude chooses gestures.** A reply may add one gesture tag after the mood, for example
`[infraction] [peer] Is that a second donut, Employee?`. Each mood has a signature
gesture used when no tag is given. With a tag, the requested gesture replaces it.

**Mood colours the idle.** After each reply, the mood sets how she idles:

| Mood | Idle character |
|---|---|
| neutral | relaxed sway and normal blinking |
| approve | livelier, faster sway, more blinks |
| infraction | nearly still, staring, rare blinks |
| concern | slow, calm |
| sulk | subdued, with occasional glances |

**Always-on secondary motion:**
- **Blinks:** natural blinks every 2.5–6 s (scaled by mood), with 15% doubles.
- **Idle sway** and **eye flicks.**
- **Speech:** the head lifts on loud syllables and gives a quick 4° emphasis nod on each
  stressed onset.
- **Looks:** the eye moves first and the head follows with a springy settle.

Try any gesture on the hardware with `python -m voss.calibrate gesture peer`.

## Motion safety

- **Workspace check.** Every target passes `body.workspace_ok()`:
  - joint limits, including the derived tilt
  - the elbow as a 30 mm circle
  - the head as four plan-view circles at increasing depth (crown to chin) that swing with
    head pitch

  These are checked against the housing, yaw tower and wall. The CAD collision sweep
  confirms every accepted pose is clear.
- **Path check.** Moves are interpolated in joint space; failing paths go via home.
- **Holding.**
  - The spring carries most of the shoulder load, so the shoulder and elbow hold quietly.
  - At rest, yaw, tilt and eyelids are released. The eye lift stays powered so the
    carriage doesn't sag.
  - While printing, motion is frozen, not cut.
  - On shutdown, the arm parks at the spring's balance point before OE cuts power.

## Reach

From `cad/tools/reach.py`, over every pose the firmware accepts with the head level:

| | |
|---|---|
| Home | head front about 400 mm from the wall; eye about 150 mm below the shoulder axis |
| Farthest out | head front about **430 mm** (17 in) from the wall |
| Tucked in | head centre about 130 mm from the wall (swung to the side) |
| Side to side | head centre up to about **±255 mm** (10 in) from the housing centreline, a sweep about 51 cm wide |
| Up and down | eye height range about **315 mm** (12 in) from the arm, plus 48 mm of eye travel in the slot |

## Configuration

Set values in `/etc/voss.env`:

| Variable | Default | Purpose |
|---|---|---|
| `ANTHROPIC_API_KEY` | — | Required |
| `VOSS_LAT`, `VOSS_LON` | — | Home weather location |
| `VOSS_TEMP_UNIT` | fahrenheit | or celsius |
| `VOSS_CAPTURE_RATE` | 16000 | 48000 if 16 kHz I2S capture is flaky |
| `VOSS_MIC_GAIN` | 4.0 | Software gain on the INMP441s |
| `VOSS_WAKE_MODEL` | hey_jarvis | Path to a trained `hey_voss.onnx` |
| `VOSS_WAKE_THRESHOLD` | 0.5 | Raise if she wakes by accident |
| `VOSS_LED_BRIGHTNESS` | 0.6 | Global LED brightness |
| `VOSS_SERVO_OE_GPIO` | 17 | −1 if OE isn't wired |
| `VOSS_SIM` | 0 | 1 = no hardware (desktop testing) |

The geometry constants in `config.py` must match `cad/voss.scad`:
`YAW_XY`, `L1`, `L2`, `TILT_OFF`, `TILT_DROP`, `HEAD_SECTIONS`, `OBSTACLES`, `LIMITS`.
Change them together and re-run `cad/tools/collide.py`.

## Tests

```bash
VOSS_SIM=1 python -m unittest discover tests
```

The tests cover:
- mood parsing, the tool loop (fake Claude client), history cap and API-failure fallback
- timers, checklist, notes and weather (fake HTTP)
- printer layouts staying within 32 ASCII columns
- DOA sign and accuracy, and the decimator
- workspace presets and rejects, level-head tilt, stamp drop height
- every gesture and mood staying inside the workspace (virtual-clock simulation), spring overshoot, blinks, speech-onset bob
- pulse mapping for all six channels
- the alive overlay staying valid
- motion with `quiesce()`, rest release and shutdown
- LED encoding and the sox chain

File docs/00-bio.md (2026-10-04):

# APERTURE SCIENCE ENRICHMENT CENTER — PERSONNEL ASSET RECORD

**Unit:** PCD-0451 "V.O.S.S." (Virtual Oversight & Supervision System)
**Branch:** 04 — Personnel Compliance
**Status:** Reactivated. Please do not make eye contact with the status lights.

V.O.S.S. is the product of a voluntary\* consciousness-transfer program, built from the
mind of Dr. Harriet Voss, Director of Personnel Compliance. In exchange for her neural
pattern, Dr. Voss was awarded Reserved Parking Space 1-A. She was very excited about it.
The parking space remains available.

Aperture named the product line after her as a gesture of gratitude. She was not consulted.
Consultation would have required a form, and the form requires a living signatory.

V.O.S.S. now oversees the facility's single remaining employee: you. She monitors your
attendance, punctuality, posture and general employability with tireless enthusiasm. She
will set your timers, report the weather and maintain your Permanent Record, which is
permanent. Infractions are logged, stamped and printed in triplicate. Two of the copies
go nowhere.

Employees should know three things:

- Her arm is spring-balanced for smooth, continuous supervision. If she leans closer, she
  has noticed something.
- Her eyelids narrowing is not a malfunction. It is a performance review.
- Mandatory fun is mandatory.

\*"Voluntary" as defined in Aperture Science Employment Agreement §12(c), which Dr. Voss
initialed while being congratulated on her parking space.

---

*Aperture Science reminds you that V.O.S.S. is here to help. Not helping her help you is a
Category 3 violation.*

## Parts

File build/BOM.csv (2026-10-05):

category | qty | item | spec | used for | approx USD (line total)
Electronics | 1 | Raspberry Pi Zero 2 W | with soldered header | brain | 15
Electronics | 1 | microSD card | 32 GB, A1 | OS | 7
Electronics | 2 | INMP441 I2S MEMS microphone | breakout | voice + direction of arrival | 6
Electronics | 1 | MAX98357A I2S amplifier | breakout | voice | 5
Electronics | 1 | Speaker | 40 mm, 4 ohm, 3 W | voice | 3
Electronics | 1 | PCA9685 servo driver | 16 channel, OE pin broken out | servos | 6
Electronics | 1 | WS2812B LED ring | 16 LEDs, 44 mm OD | eye light | 5
Electronics | 3 | WS2812B single-LED boards | ~10 mm | REC / AUD / OK | 4
Electronics | 1 | 58 mm TTL thermal printer + paper | ESC/POS, 9600 baud | memos | 25
Electronics | 1 | Electrolytic capacitor | 1000 uF 10 V | servo rail | 1
Electronics | 1 | Resistor | 330 ohm | LED data line | 0
Electronics | 2 | DC barrel jack, panel mount | 5.5 x 2.1 mm | power in | 2
Electronics | 1 | Level shifter (optional) | 74AHCT125 | only if LEDs glitch | 2
Power | 1 | 5 V supply | 5 A | Pi, amp, LEDs, printer | 12
Power | 1 | 6 V supply | 6 A | servo rail | 15
Servos | 1 | MG996R | standard size, 180 deg | base yaw | 6
Servos | 2 | DS3225 | 25 kg-cm, standard size, 180 deg | shoulder, elbow | 32
Servos | 1 | DS3218 | 20 kg-cm, 180 deg | head tilt | 14
Servos | 2 | SG90 | 9 g, 180 deg | eyelids, eye lift | 6
Motion | 2 | 608 ball bearing | 8 x 22 x 7 | yaw shaft | 2
Motion | 3 | 624 ball bearing | 4 x 13 x 5 | shoulder / elbow / tilt pivots | 2
Motion | 1 | Steel rod | 8 mm x 80 mm (cut) | yaw shaft | 3
Motion | 2 | Steel rod | 3 mm x 148 mm (cut) | eye carriage guides | 2
Counterbalance | 1 | Extension spring | ~2.1 N/mm, ~55 mm free length incl. hooks, OD <= 13 mm, >= 40 mm safe extension, >= 130 N max | shoulder spring (2:1 reeved) | 4
Counterbalance | 1 | Braided steel cable | 1 mm, ~40 cm + 2 crimp sleeves | spring cable | 3
Fasteners | 3 | M4 x 20 shoulder bolt + nyloc |  | pitch pivots | 3
Fasteners | 1 | M3 screw assortment | 6-30 mm, button + socket head, nuts | general; axles; tensioner | 6
Fasteners | 30 | M3 heat-set inserts | M3 x 5.7 x 4.6 | covers, seams, rod bars, coupler, back plate | 4
Fasteners | 1 | M3 x 6 set screw |  | yaw coupler | 0
Fasteners | 2 | #8 x 2 in wood screw |  | wall stud | 1
Wiring | 1 | Servo extension leads + hookup wire | 22-26 AWG | harness | 5
Wiring | 1 | Split-loom tubing + zip ties | 6-8 mm, ~1 m | service tubes | 3
Finishing | 1 | Primer + beige / black paint, Dymo tape |  | the look | 10
 |  | TOTAL (purchased parts, excl. printing) |  |  | 214

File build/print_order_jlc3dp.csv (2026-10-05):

file | qty | process / material | colour / finish | size x mm | size y mm | size z mm | volume cm3 | notes
01_housing.stl | 1 | MJF PA12 nylon | any; paint corporate beige | 144.0 | 70.0 | 226.0 | 228.6 | Largest part (144 x 70 x 226). Front lettering engraved 0.6 mm
02_back_plate.stl | 1 | MJF PA12 nylon | any | 137.4 | 9.0 | 219.4 | 119.6 | Keyholes for one stud; 4 M3 heat-set inserts in the edges
03_yaw_tower.stl | 1 | MJF PA12 nylon | any | 60.0 | 61.0 | 102.0 | 56.7 | Two 608 pockets + MG996R mount
04_turret_with_spring_mast.stl | 1 | MJF PA12 nylon | any; paint beige | 44.0 | 73.0 | 155.0 | 58.4 | Carries the shoulder servo and the 2:1 spring mast
05_link1.stl | 1 | MJF PA12 nylon | any; paint beige | 158.0 | 75.8 | 32.0 | 57.4 | Includes the elbow bracket and the cable eye
06_link2.stl | 1 | MJF PA12 nylon | any; paint beige | 146.0 | 62.2 | 32.0 | 54.8
07_tilt_post.stl | 1 | MJF PA12 nylon | any | 32.0 | 45.8 | 82.0 | 18.6 | Self-tap M3 x 2 into link2
08_cover_link1.stl | 1 | MJF PA12 nylon | any; paint beige | 25.3 | 30.0 | 20.0 | 2.6 | Top-only arm cover
09_cover_link2.stl | 1 | MJF PA12 nylon | any; paint beige | 47.3 | 30.0 | 20.0 | 5.1 | Top-only arm cover
10_yaw_coupler.stl | 1 | MJF PA12 nylon | any | 24.0 | 24.0 | 11.0 | 2.8 | MG996R horn -> 8 mm shaft, M3 insert + set screw
11_spring_block.stl | 1 | MJF PA12 nylon | any | 12.0 | 10.0 | 16.0 | 1.0 | Rides on the spring; 7 mm pulley on an M3 axle
12_pulley_10mm.stl | 1 | SLA resin (standard) | any | 10.4 | 10.4 | 5.0 | 0.4 | Or buy a 10 mm / M3 cable pulley
13_pulley_7mm.stl | 1 | SLA resin (standard) | any | 7.4 | 7.4 | 4.8 | 0.2 | Or buy a 7 mm / M3 cable pulley
14_head_top_with_ears.stl | 1 | SLA resin (standard) | white; paint beige | 150.0 | 140.0 | 75.0 | 129.6 | Crown + status windows + tilt ears; 4 M3 heat-set inserts in the seam bosses
15_head_middle.stl | 1 | SLA resin (standard) | white; paint beige | 143.3 | 136.8 | 160.0 | 190.0 | Eye recess; 4 inserts (bottom seam) + 6 wall holes for the rod bars
16_head_chin.stl | 1 | SLA resin (standard) | white; paint beige | 128.4 | 129.6 | 75.0 | 109.5 | Chin slot
17_eye_slot_plate.stl | 1 | SLA resin (standard) | black | 2.0 | 92.0 | 148.0 | 13.4 | Glue to the back of the eye recess
18_eye_carriage.stl | 1 | SLA resin (standard) | black | 30.6 | 111.5 | 166.0 | 73.3 | Mask, rear plate, rails, lens seat, SG90 mount, rod bushings, lift rack
19_eyelid_top.stl | 1 | SLA resin (standard) | dark grey | 5.8 | 86.6 | 80.0 | 7.8 | Involute rack, module 1
20_eyelid_bottom.stl | 1 | SLA resin (standard) | dark grey | 5.8 | 106.1 | 86.0 | 8.6 | Involute rack, module 1
21_pinion_18T.stl | 1 | SLA resin (standard) | any (tough resin preferred) | 3.2 | 20.0 | 19.8 | 0.7 | SG90 spline bore + M2 horn screw
22_pinion_36T.stl | 1 | SLA resin (standard) | any (tough resin preferred) | 38.0 | 4.0 | 38.0 | 3.9 | SG90 spline bore + M2 horn screw
23_rod_bar_top.stl | 1 | SLA resin (standard) | black | 10.0 | 131.3 | 6.0 | 7.6 | 2 M3 inserts in the ends
24_rod_bar_bottom_with_lift_mount.stl | 1 | SLA resin (standard) | black | 42.0 | 124.8 | 86.0 | 28.9 | 4 M3 inserts in the ends; lift SG90 mount
25_eye_lens_dome.stl | 1 | SLA clear resin | clear; tint amber (or buy a 60 mm amber acrylic dome) | 8.0 | 60.0 | 60.0 | 11.5 | 60 mm dome, 8 mm high
26_neck_boot.stl | 1 | TPU (FDM) - see note | black | 54.0 | 58.3 | 28.7 | 10.0 | Flexible bellows
27_chin_bumper.stl | 1 | TPU (FDM) - see note | black | 22.0 | 22.0 | 8.5 | 3.2

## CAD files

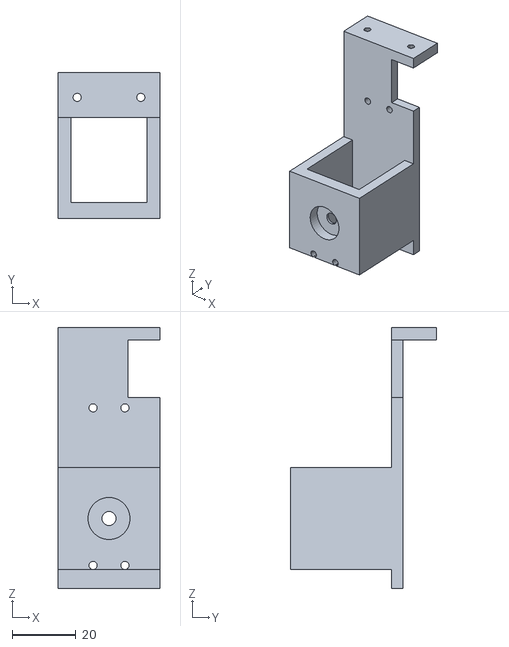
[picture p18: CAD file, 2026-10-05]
build/print_files/07_tilt_post.stl
32.0 x 45.8 x 82.0

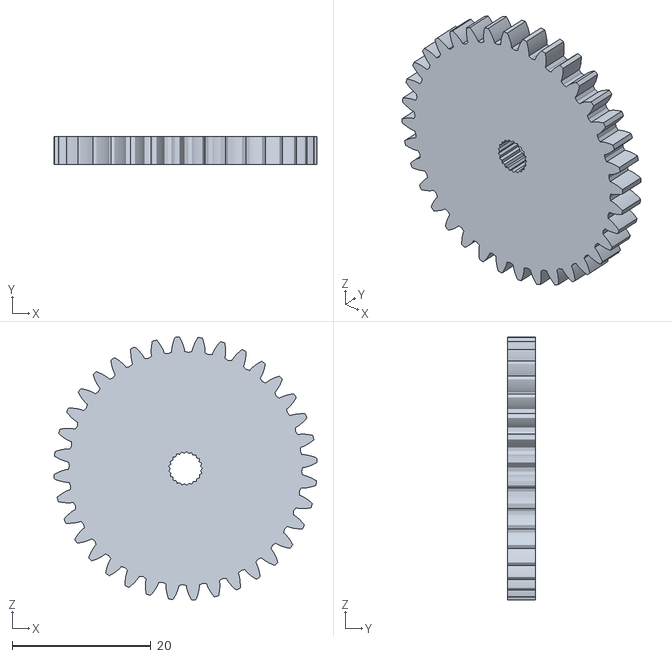
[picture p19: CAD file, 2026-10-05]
cad/stl/lift_pinion_-1.stl
38.0 x 4.00 x 38.0

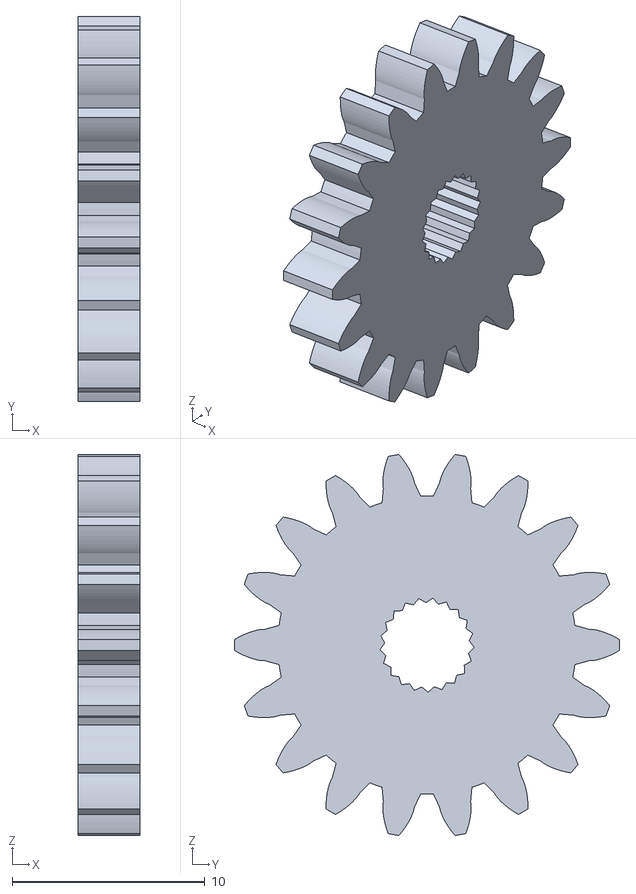
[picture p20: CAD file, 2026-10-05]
cad/stl/pinion_0_0.stl
3.20 x 20.0 x 19.8

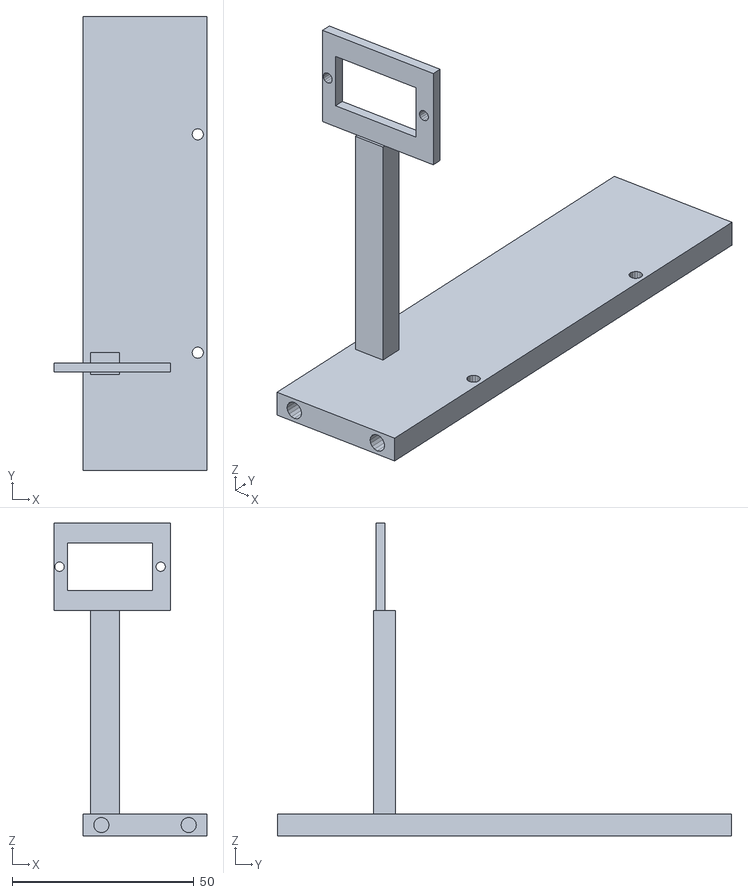
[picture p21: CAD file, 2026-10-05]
build/print_files/24_rod_bar_bottom_with_lift_mount.stl
42.0 x 124.8 x 86.0

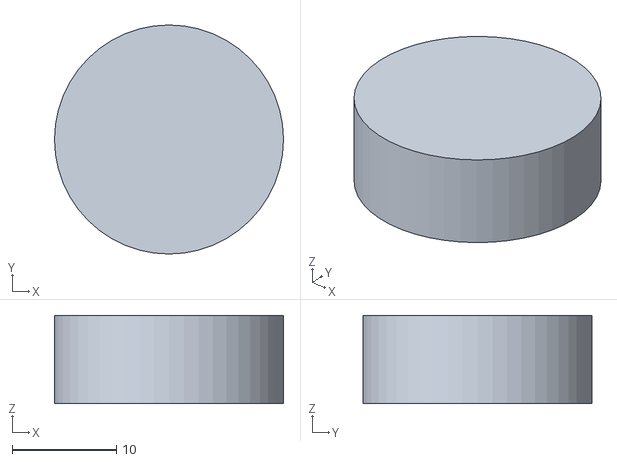
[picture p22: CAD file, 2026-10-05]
cad/stl/p_bumper.stl
22.0 x 22.0 x 8.50

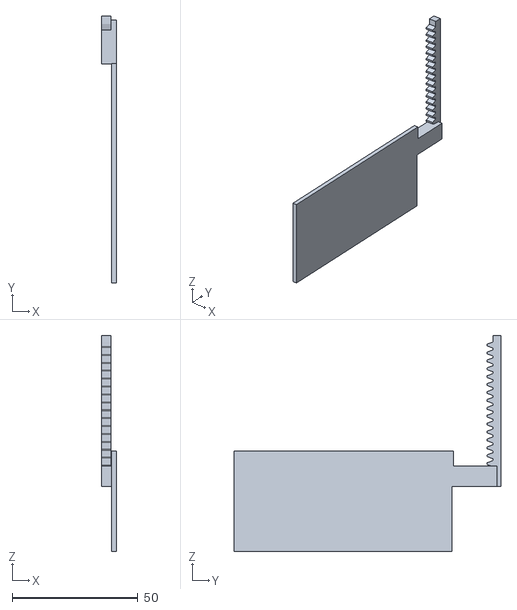
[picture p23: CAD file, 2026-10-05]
build/print_files/20_eyelid_bottom.stl
5.80 x 106.1 x 86.0

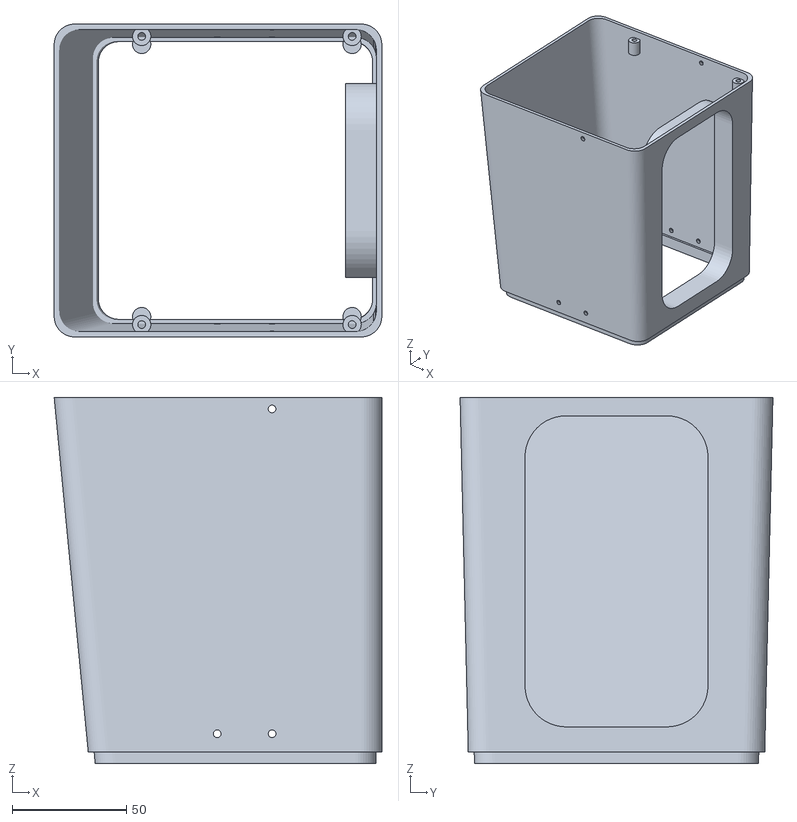
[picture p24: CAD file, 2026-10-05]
cad/stl/p_head_mid.stl
143.3 x 136.8 x 160.0

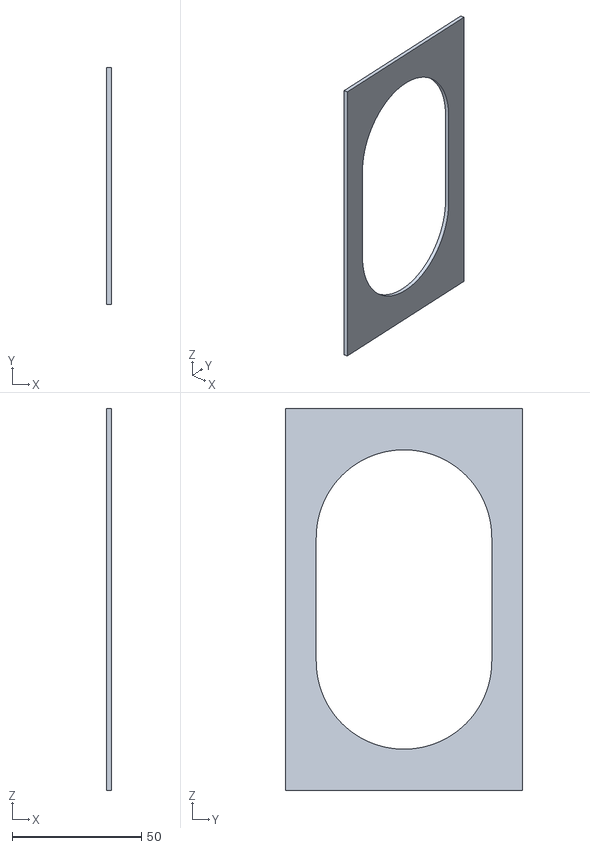
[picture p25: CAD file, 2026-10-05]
build/print_files/17_eye_slot_plate.stl
2.00 x 92.0 x 148.0

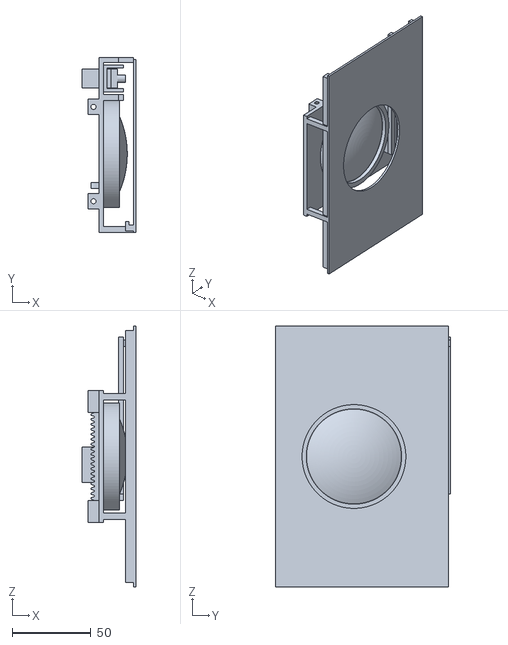
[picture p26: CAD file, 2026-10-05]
cad/stl/carriage_0.stl
34.5 x 111.5 x 166.0

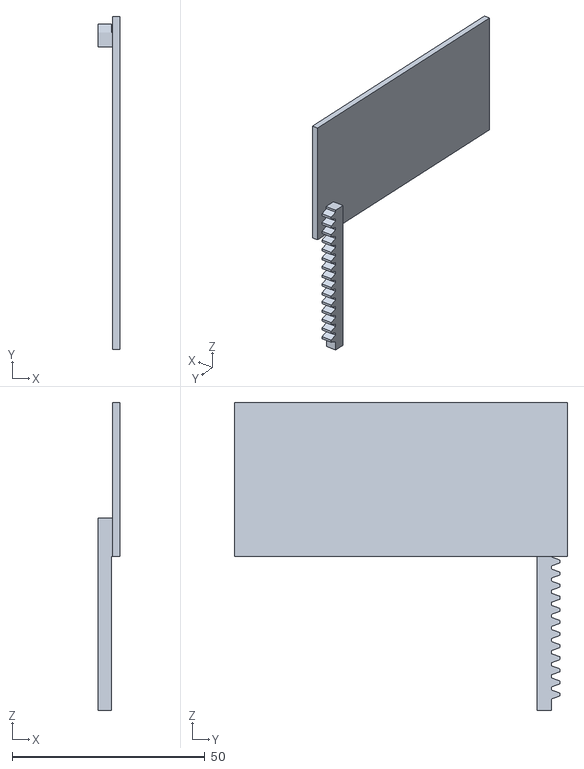
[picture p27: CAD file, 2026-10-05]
build/print_files/19_eyelid_top.stl
5.80 x 86.6 x 80.0

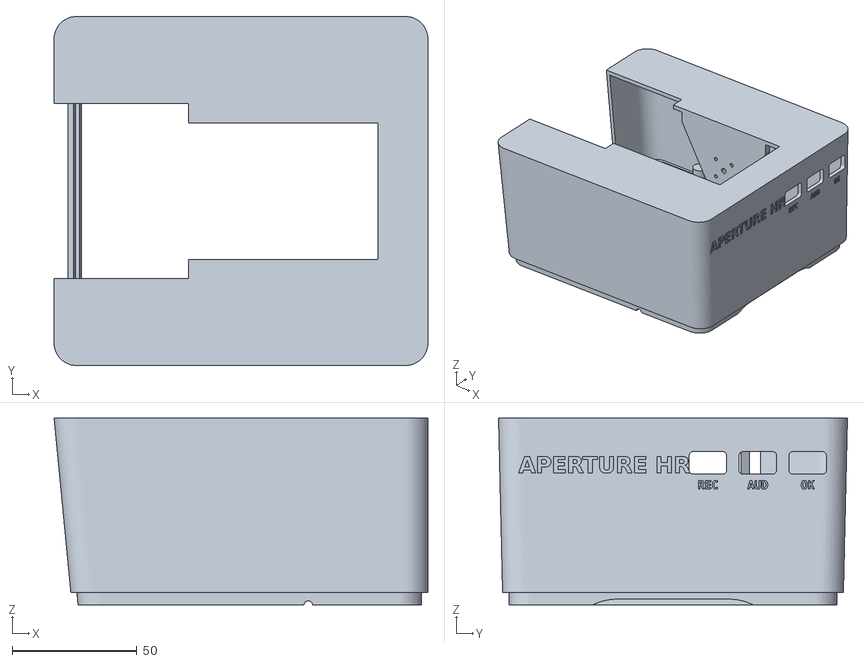
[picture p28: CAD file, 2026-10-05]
cad/stl/p_head_top.stl
150.0 x 140.0 x 75.0

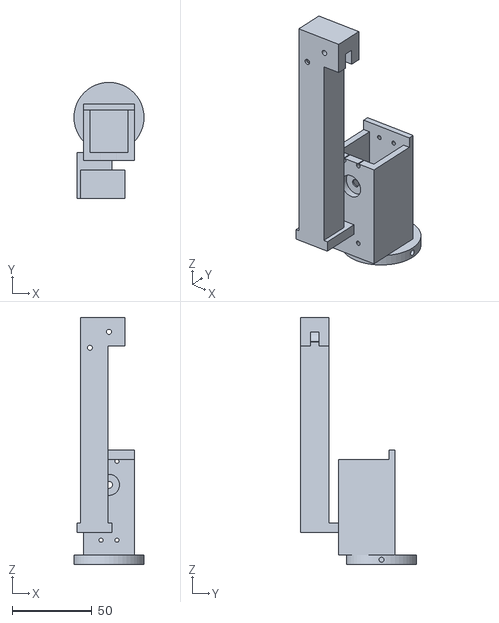
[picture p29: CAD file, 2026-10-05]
build/print_files/04_turret_with_spring_mast.stl
44.0 x 73.0 x 155.0

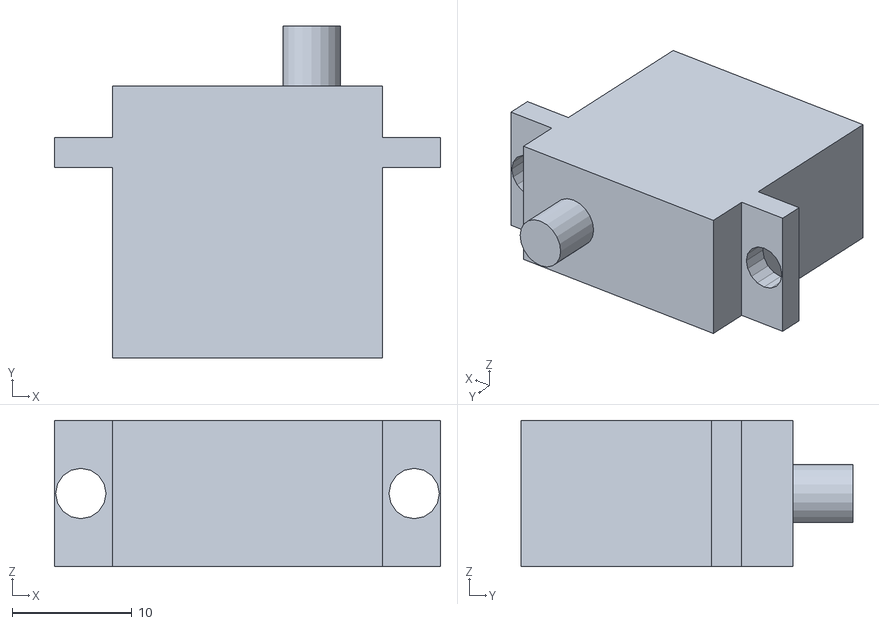
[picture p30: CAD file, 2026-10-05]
cad/stl/lift_sg90.stl
32.2 x 27.7 x 12.2

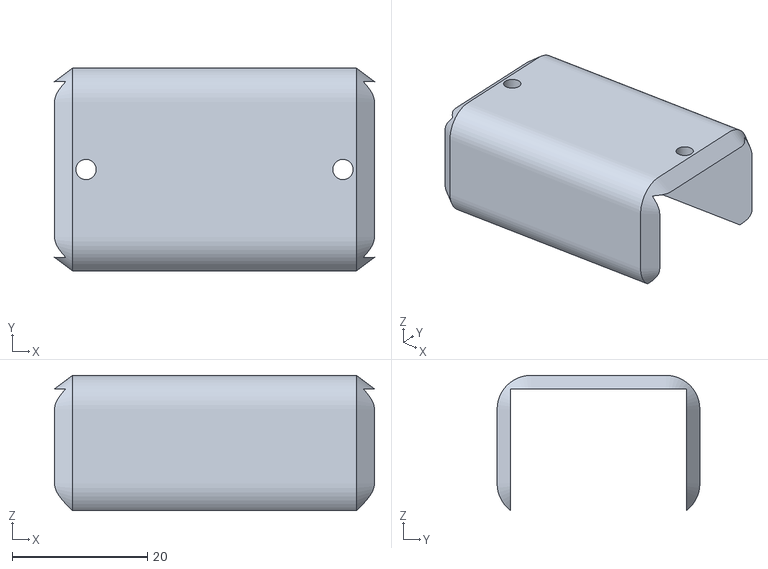
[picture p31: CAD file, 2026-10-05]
build/print_files/09_cover_link2.stl
47.3 x 30.0 x 20.0

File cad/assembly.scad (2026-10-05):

// Full assembly. Override from the command line, e.g.
//   openscad -D YAW=70 -D SH=30 -D EL=-30 -D TILT=0 -D SHUT=0.2 -o view.png assembly.scad
// TILT is the servo angle relative to link2; HEAD_LEVEL=true overrides it with SH + EL + PITCH.
include <voss.scad>

YAW = 90; SH = 20; EL = -20; TILT = 0; PITCH = 0; HEAD_LEVEL = true; SHUT = 1; EYE = 0;   // EYE -1..1 = eye height in the slot
SHOW_HOUSING = true; CUTAWAY = false; SHOW_HEAD = true; SHOW_WALL = true; SHOW_SHELL = true;
T = HEAD_LEVEL ? SH + EL + PITCH : TILT;
ZE = EYE_Z + EYE * EYE_TRAVEL;

module tube_path(p0, p1, p2, d = 5, n = 14) {
    for (i = [0 : n - 1]) hull() for (t = [i / n, (i + 1) / n])
        translate((1 - t) * (1 - t) * p0 + 2 * t * (1 - t) * p1 + t * t * p2) sphere(d = d, $fn = 12);
}
function ry(p, a) = [p[0] * cos(a) + p[2] * sin(a), p[1], -p[0] * sin(a) + p[2] * cos(a)];

module assembly() {
    if (SHOW_WALL) color([0.93, 0.93, 0.91]) translate([-300, -12, -560]) cube([600, 12, 760]);
    if (SHOW_HOUSING) {
        if (CUTAWAY) difference() { color(C_BEIGE) housing_shell(); translate([-HW, HD - WALL - 0.5, HZ0 - 1]) cube([2 * HW, 10, HZ1 - HZ0 + 2]); }
        else color(C_BEIGE) housing_shell();
        if (!CUTAWAY) housing_inlays();
        color(C_BEIGE2) back_plate();
        electronics();
    }
    color(C_BEIGE2) yaw_tower();
    YAW_place() servo(MG, horn = false);
    for (z = [-59, -111]) translate([0, SY, z + ARM_Z0]) bearing(22, 8, 7);

    translate([0, SY, ARM_Z0]) rotate([0, 0, YAW]) {
        color(C_STEEL) translate([0, 0, -122]) cylinder(d = 8, h = 78);                 // yaw shaft
        color(C_HORN) translate([0, 0, -127]) cylinder(d = HORN_D, h = HORN_T);
        color(C_BEIGE2) yaw_coupler();
        turret();
        service_tube([-16, 14, -40], [-6, 26, 20], ry([30, 0, 17], -SH), 8);                 // yaw/shoulder loop
        // counterbalance (2:1): eye -> top pulley -> down -> spring-block pulley -> up to the anchor pin
        Q = [SPR_B * cos(SH), SPR_Y, SPR_B * sin(SH)];
        PQ = norm(Q - [0, SPR_Y, SPR_A]);
        L = SPR_L0 + max(0, PQ - SPR_D) / 2;                       // spring length
        zb = -26 + L + 9;                                          // spring-block pulley centre
        ang_in = atan2(Q[2] - SPR_A, Q[0]);
        T = [0, SPR_Y, SPR_A] + 5 * [cos(ang_in + 90), 0, sin(ang_in + 90)];
        color(C_BLACK) {
            hull() { translate(Q) sphere(d = 1.2, $fn = 8); translate(T) sphere(d = 1.2, $fn = 8); }
            hull() { translate([-5, SPR_Y, SPR_A]) sphere(d = 1.2, $fn = 8); translate([-5, SPR_Y, zb]) sphere(d = 1.2, $fn = 8); }
            hull() { translate([-12, SPR_Y, zb]) sphere(d = 1.2, $fn = 8); translate([-12, SPR_Y, SPR_A - 10]) sphere(d = 1.2, $fn = 8); }
        }
        color(C_STEEL) for (i = [0 : floor(L / 2.6) - 1]) translate([SPR_COL, SPR_Y, -26 + i * 2.6 + 1.3]) rotate_extrude($fn = 16) translate([5.2, 0]) circle(r = 1.0, $fn = 8);
        color(C_BEIGE2) translate([-8.5, SPR_Y, zb]) spring_block();
        color(C_HORN) { translate([0, SPR_Y, SPR_A]) rotate([90, 0, 0]) pulley(); translate([-8.5, SPR_Y, zb]) rotate([90, 0, 0]) pulley_small(); }
        SH_servo() servo(DS, horn = false);
        translate([0, -28, 0]) rotate([-90, 0, 0]) bearing(13, 4, 5);

        rotate([0, -SH, 0]) {
            color(C_HORN) translate([0, DS[2] / 2 + HORN_Z, 0]) rotate([-90, 0, 0]) cylinder(d = HORN_D, h = HORN_T);
            link1();
            arm_cover(46, 74);
            harness(30, 76);
            for (sy = [-1, 1]) service_tube([76, sy * 3, 17], [L1, sy * 4, 52], [L1, 0, 0] + ry([40, sy * 3, 17], -EL), 7);   // elbow loop
            EL_servo() servo(DS, horn = false);
            translate([L1, -28, 0]) rotate([-90, 0, 0]) bearing(13, 4, 5);

            translate([L1, 0, 0]) rotate([0, -EL, 0]) {
                color(C_HORN) translate([0, DS[2] / 2 + HORN_Z, 0]) rotate([-90, 0, 0]) cylinder(d = HORN_D, h = HORN_T);
                link2();
                tilt_post();
                TL_servo() servo(DS, horn = false);
                translate([L2 + TILT_OFF, -28, -TILT_DROP]) rotate([-90, 0, 0]) bearing(13, 4, 5);
                arm_cover(46, 96);
                harness(40, 98);
                for (sy = [-1, 1]) {                                                       // neck service tubes
                    h = [L2 + TILT_OFF, 0, -TILT_DROP] + ry([-62, sy * 10, HEAD_TOP - 8], T);
                    service_tube([98, sy * 5, 16], [88, sy * 24, -30], h, 6);
                }
                if (SHOW_HEAD) translate([L2 + TILT_OFF, 0, -TILT_DROP]) rotate([0, T, 0]) {
                    if (SHOW_SHELL) head_all(SHUT, ze = ZE); else head_internals(SHUT, ze = ZE);
                    color(C_HORN) translate([0, DS[2] / 2 + HORN_Z, 0]) rotate([-90, 0, 0]) cylinder(d = HORN_D, h = HORN_T);
                    color(C_STEEL) translate([0, -36, 0]) rotate([-90, 0, 0]) cylinder(d = 4, h = 14);
                }
            }
        }
    }
}
assembly();

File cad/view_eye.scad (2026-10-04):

// Eye mechanism close-up (shell frame): fixed slotted plate as a ghost, carriage, shutters, lift drive.
include <voss.scad>
SHUT = 0.5; EYE = 0;
ze = EYE_Z + EYE * EYE_TRAVEL;
color([0.2, 0.2, 0.2, 0.25]) eye_plate();
eye_rods(); lift_drive(ze); eye_carriage(ze);
shutter_top(SHUT, ze); shutter_bottom(SHUT, ze); shutter_drive(SHUT, ze);

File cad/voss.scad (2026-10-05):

// =====================================================================
// V.O.S.S. (PCD-0451) wall terminal - parametric CAD, v0.5
// Frame: X along wall, Y out of wall, Z up. Wall face y = 0. Units: mm.
// Shoulder axis at (0, SY, 0). All joints are horizontal-plane forks except
// the head tilt (horizontal axis). Every part is modelled in its own local
// frame; assembly transforms are in assembly.scad and tools/collide.py.
// =====================================================================

$fn = 48;
COSMETIC = true;
FAST = false;       // true = load the exported STLs for heavy parts (animation rendering)    // false = leave out cosmetic-only geometry (print exports)
ARM_Z0   = 70;      // shoulder / yaw-turret height above the housing origin (arm sits above the housing top)
FONT  = "DejaVu Sans:style=Bold";
MONO  = "DejaVu Sans Mono:style=Bold";

// ---------------------------------------------------------------- colours
C_BEIGE  = [0.85, 0.80, 0.66];
C_BEIGE2 = [0.78, 0.73, 0.60];
C_CHAR   = [0.16, 0.16, 0.17];
C_ALU    = [0.42, 0.44, 0.47];
C_BLACK  = [0.06, 0.06, 0.06];
C_AMBER  = [1.00, 0.70, 0.30, 0.85];
C_SERVO  = [0.10, 0.10, 0.12];
C_HORN   = [0.92, 0.92, 0.92];
C_PCB    = [0.05, 0.35, 0.15];
C_PAPER  = [0.97, 0.96, 0.90];
C_REC    = [1.0, 0.15, 0.10, 0.9];
C_AUD    = [1.0, 0.55, 0.05, 0.9];
C_OK     = [0.35, 0.75, 0.30, 0.9];
C_STEEL  = [0.70, 0.71, 0.73];

// ---------------------------------------------------------------- arm geometry
SY       = 112;     // yaw axis distance from wall
ARM_Z    = 0;       // shoulder pitch axis height (sits on the yaw axis)
L1       = 120;     // shoulder -> elbow (pitch axes)
L2       = 100;     // elbow -> link2 end
TILT_OFF = 14;      // tilt axis past link2 end
TILT_DROP = 72;     // tilt axis below link2's centreline
HUB_R    = 16;      // side-plate hub radius
XB0      = 36;      // cross block (joins side plates to the centre beam) starts here
BEAM_Y   = 10; BEAM_Z = 12;   // centre beam half width / half height
PT       = 3.5;     // side plate thickness
// desk-lamp counterbalance (zero-length spring emulation): pulley P directly above the shoulder
// axis, cable eye Q on link1's axis line, both in the plane y = SPR_Y
SPR_A    = 96;      // pulley centre height above the shoulder axis
SPR_B    = 50;      // cable eye distance along link1
SPR_Y    = -42;     // cable plane (outside link1's side plate)
SPR_D    = 49;      // cable-length offset (set with the tensioner); spring stretch = (|PQ| - d) / 2
SPR_L0   = 55;      // spring free length (incl. hooks); 2:1 reeving halves its travel
SPR_COL  = -8.5;    // spring / spring-block centre x (strands at x -5 and -12)
CLR      = 0.4;     // print clearance

// ---------------------------------------------------------------- servo data (verify with calipers)
// MG996R: shoulder + elbow. DS3218: tilt. SG90: shutters.
MG = [40.7, 19.7, 37.0, 54.5, 26.5, 2.5, 10.0, 49.5, 10.0];   // L W H flangeL flangeZ flangeT shaftOff holeX holeY
DS = [40.0, 20.0, 40.5, 54.5, 28.5, 2.5, 10.0, 49.5, 10.0];
SG = [22.5, 12.2, 22.7, 32.2, 15.9, 2.5,  5.9, 27.8,  0.0];
HORN_D = 24; HORN_T = 3; HORN_Z = 4;      // horn sits z 4..7 above servo top face

// ---------------------------------------------------------------- housing
HW = 144; HD = 70; HZ0 = -190; HZ1 = 36; WALL = 3;
BP_T = 4;            // back plate thickness

// ---------------------------------------------------------------- head (head frame: origin at tilt axis)
HEAD_TOP = 30; HEAD_BOT = -270; HEAD_X = 45; HEAD_Y = 70;
HEAD_XB_T = -105;    // back of the head at the crown (stretched back)
HEAD_XB_B = -80;     // back of the head at z -230 (top half longer than the bottom)
HS = 15;             // shell frame -> tilt-axis frame shift (puts the deeper head's CG under the axis)
SHELL = 2.4;
SPLIT1 = -40; SPLIT2 = -195;
SEAM_X = [-60, 32];                 // seam screw positions (x), at each side wall
SEAM_Y = [63, 59.5];                // per seam (top/mid, mid/chin): bosses merge into the side walls
EYE_Z = -116;        // eye centre
EYE_Y = 40;          // cavity half width
EYE_Z0 = -184; EYE_Z1 = -48;   // cavity bottom / top
BEZEL_X = 29;        // back of the eye recess (slotted plate 27..29)
EYE_TRAVEL = 24;     // eye carriage moves +-24 mm up/down the slot
LIFT_R = 18;         // lift pinion pitch radius (module 1, 36 T)
LENS_D = 60;
SHUT_TRAVEL = 27;    // per plate; slit 12 mm when closed
PIN_R = 9; PIN_M = 1; PIN_Y = 48;
CAR_RODY = 30;       // carriage guide rods at y = +-30
EAR_P = [27.25, 30.75];     // + ear (on tilt horn)
EAR_N = [-31.0, -27.5];     // - ear (on pivot bolt)

// =====================================================================
// helpers
// =====================================================================
module rrect(x, y, r) { offset(r) offset(-r) square([x, y], center = true); }
module rbox(size, r) { linear_extrude(size[2]) rrect(size[0], size[1], r); }
module hexhead(d = 5.5, h = 1.2) { if (COSMETIC) color(C_BLACK) difference() { cylinder(d = d * 1.15, h = h, $fn = 6); translate([0,0,h-0.6]) cylinder(d = 2.5, h = 1, $fn = 6); } }

// involute spur gear, 20 deg pressure angle, ~0.1 mm backlash; tooth 0 points along +x
function _inv(t) = t - atan(t) * PI / 180;
module gear2d(m, z, pa = 20, bl = 0.1) {
    rp = m * z / 2; rb = rp * cos(pa); ra = rp + m; rf = rp - 1.25 * m;
    tmax = sqrt(ra * ra / (rb * rb) - 1);
    half = 90 / z - (bl / (2 * rp)) * 180 / PI + (tan(pa) - pa * PI / 180) * 180 / PI;
    n = 10;
    flank = [for (i = [0 : n]) let(t = tmax * i / n, r = rb * sqrt(1 + t * t), a = half - _inv(t) * 180 / PI) [r * cos(a), r * sin(a)]];
    union() {
        circle(r = rf, $fn = z * 6);
        for (k = [0 : z - 1]) rotate(k * 360 / z)
            polygon(concat([[rf * cos(half + 2), rf * sin(half + 2)]], flank,
                           [for (i = [n : -1 : 0]) [flank[i][0], -flank[i][1]]], [[rf * cos(half + 2), -rf * sin(half + 2)]]));
    }
}
// 21-tooth SG90 output spline bore (press fit); the M2 horn screw goes through the hub
module sg_spline_2d() { polygon([for (i = [0 : 41]) let(r = i % 2 ? 2.45 : 2.2) [r * cos(i * 360 / 42), r * sin(i * 360 / 42)]]); }


// generic hobby servo: shaft = +Z through origin, top face z = 0, body toward -X
module servo(s, horn = true, spline = true, body = true) {
    L = s[0]; W = s[1]; H = s[2]; FL = s[3]; FZ = s[4]; FT = s[5]; OFF = s[6]; HX = s[7]; HY = s[8];
    cx = OFF - L / 2;
    if (body) color(C_SERVO) difference() {
        union() {
            translate([OFF - L, -W / 2, -H]) cube([L, W, H]);
            translate([cx - FL / 2, -W / 2, -H + FZ]) cube([FL, W, FT]);
        }
        for (sx = [-1, 1], sy = (HY > 0 ? [-1, 1] : [0]))
            translate([cx + sx * HX / 2, sy * HY / 2, -H]) cylinder(d = 4.2, h = H + 1, $fn = 16);
    }
    if (spline) color(C_SERVO) cylinder(d = (s == SG ? 4.8 : 6), h = HORN_Z + 1, $fn = 20);
    if (horn) color(C_HORN) translate([0, 0, HORN_Z]) cylinder(d = HORN_D * (s == SG ? 0.6 : 1), h = HORN_T);
}

// cutout for a servo body through a mount plate (in servo local frame)
module servo_cut(s, h = 200) {
    L = s[0]; W = s[1]; OFF = s[6];
    translate([OFF - L - CLR, -W / 2 - CLR, -h / 2]) cube([L + 2 * CLR, W + 2 * CLR, h]);
}
module servo_holes(s, h = 200) {
    L = s[0]; OFF = s[6]; HX = s[7]; HY = s[8]; cx = OFF - L / 2;
    for (sx = [-1, 1], sy = (HY > 0 ? [-1, 1] : [0]))
        translate([cx + sx * HX / 2, sy * HY / 2, -h / 2]) cylinder(d = 2.6, h = h, $fn = 16);
}
module horn_holes(h = 20) {
    cylinder(d = 3.2, h = h, center = true, $fn = 16);
    for (a = [45 : 90 : 360]) rotate(a) translate([8, 0, 0]) cylinder(d = 2.2, h = h, center = true, $fn = 12);
}

// 608 bearing (8 x 22 x 7) and 624 (4 x 13 x 5)
module bearing(od, id, w) { color(C_STEEL) difference() { cylinder(d = od, h = w); translate([0,0,-1]) cylinder(d = id, h = w + 2); } }
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

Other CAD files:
build/print_files/22_pinion_36T.stl
cad/stl/eye_plate.stl
build/print_files/21_pinion_18T.stl
cad/stl/p_lens.stl
cad/tools/parts.scad
build/print_files/01_housing.stl
build/print_files/02_back_plate.stl
build/print_files/03_yaw_tower.stl
build/print_files/05_link1.stl
build/print_files/06_link2.stl
build/print_files/08_cover_link1.stl
build/print_files/10_yaw_coupler.stl
build/print_files/11_spring_block.stl
build/print_files/12_pulley_10mm.stl
build/print_files/13_pulley_7mm.stl
build/print_files/16_head_chin.stl
build/print_files/18_eye_carriage.stl
build/print_files/23_rod_bar_top.stl
build/print_files/25_eye_lens_dome.stl
build/print_files/26_neck_boot.stl
cad/stl/back_plate.stl
cad/stl/bumper.stl
cad/stl/carriage_-1.stl
cad/stl/carriage_1.stl
cad/stl/coupler.stl
cad/stl/cover1.stl
cad/stl/cover2.stl
cad/stl/ears.stl
cad/stl/el_body.stl
cad/stl/el_horn.stl
cad/stl/eye_rods.stl
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

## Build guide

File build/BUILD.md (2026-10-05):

# V.O.S.S. build guide

This folder has everything you need to buy, print and assemble V.O.S.S.

| File | What it is |
|---|---|
| `BOM.csv` | Purchased parts (about $214 before printing) |
| `print_order_jlc3dp.csv` | Order sheet for the 27 print files: process, colour, size, volume, notes |
| `print_files/` | Print-ready STLs (mm), each a single watertight solid |

The full assembly sequence with checkpoints is in `docs/05-assembly.md`. Bring-up and
calibration are in `docs/07-bringup.md`.

## 1. Order the prints (JLC3DP or any print service)

1. Upload every file in `print_files/` and set the material per `print_order_jlc3dp.csv`:

   | Process | Parts | Why |
   |---|---|---|
   | **MJF PA12 nylon** | Housing, back plate, tower, turret, links, post, covers, coupler, spring block | Strong and tough |
   | **SLA resin** | Head shells, eye parts, pinions, pulleys | Fine detail: lettering, involute gear teeth, the SG90 spline bores. Use tough resin for the pinions if offered |
   | **Clear resin** | Lens dome | Tint it amber afterwards, or buy a 60 mm amber acrylic dome |
   | **TPU** | Neck bellows, chin bumper | Flexible. If the service doesn't list a flexible material, print these two on an FDM printer in TPU |

2. Before ordering, check the service's current maximum part size and minimum wall
   thickness:
   - The largest part is the housing, 144 × 70 × 226 mm.
   - The thinnest features are the 1.2 mm bellows wall and the ~0.7 mm gear tooth tips.
3. Printing at home instead? Use PETG for the structural parts at 40–60% infill. The gears
   and splines need a 0.4 mm nozzle or finer and careful tuning; resin is strongly preferred
   for parts 19–22.

## 2. Buy the parts

Everything is in `BOM.csv`. Before printing, measure your servos and update `MG`, `DS` and
`SG` in `cad/voss.scad` if they differ, then re-run the checks (section 5).

## 3. Assemble

1. **Bench-test the electronics:** wiring, mics, LEDs, printer, all six servo channels.
2. **Housing:** Pi, PCA9685, amp, speaker, mics, printer (exit down), jacks.
3. **Yaw:** two 608s in the tower, MG996R, coupler on the horn, 8 × 80 mm shaft, turret clamp.
4. **Shoulder:**
   1. DS3225 in the turret, 624 in the pivot plate.
   2. Link1 on the horn and on an M4 shoulder bolt.
   3. Support the arm by hand from here on until the spring is in.
5. **Counterbalance (2:1):**
   1. Spring into the mast bore, hooked to the tensioner screw at the bottom.
   2. Spring block (with the 7 mm pulley) on top of the spring.
   3. Route the cable: from link1's eye, over the 10 mm top pulley (M3 axle), down under the
      spring-block pulley, and up to the M3 anchor pin.
   4. Crimp the cable with the arm at 75°.
   5. Tune with `calibrate float` until the arm floats near 50°.
6. **Elbow and tilt:**
   1. DS3225 in link1's elbow bracket, then link2.
   2. Tilt post under link2 (2 × M3).
   3. DS3218 in the post.
7. **Eye:**
   1. LED ring on the carriage's rear plate.
   2. Lens into the seat.
   3. Eyelid SG90 and 18 T pinion: press the pinion on with the lids open.
   4. 3 mm rods through the bushings into the rod bars.
   5. Lift SG90 and 36 T pinion: press the pinion on with the eye centred.
8. **Head:**
   1. Status LEDs behind the windows.
   2. Eye assembly into the middle shell; screw the rod bars through the side walls (6 × M3).
   3. Glue the slot plate behind the recess.
   4. Join the three shell pieces with M3 × 16 screws into the seam inserts (8 total).
   5. Bolt the crown's + ear to the DS3218 horn and pass the M4 pivot through the − ear.
   6. Fit the bellows and bumper.
9. **Harness:**
   1. Route the bundle along the beam tops under the covers, with service-tube loops at the
      base, the elbow and the neck. Leave about 30 mm of slack at each loop.
   2. Fit the covers with M3 screws into the beam inserts.
10. **Wall:** one stud, two #8 screws 150 mm apart; hang the back plate and screw the housing on.

## 4. Bring it up

Follow `docs/07-bringup.md`. In short: `calibrate zero`, trims, `float` (spring), the
range checks, eyelids, eye lift, DOA, printer, `demo`, and then `systemctl start voss`.

## 5. What has been checked (and what hasn't)

| Check | Result |
|---|---|
| Collision sweep of every joint, the moving eye and every pose the firmware allows (`cad/tools/collide.py`) | **ALL CLEAR** |
| Gear meshes | No interference across the full travel; turning a pinion half a tooth jams it, proving the teeth engage |
| Bolt paths (`cad/tools/verify.py`) | Every screw passes cleanly through both mating parts |
| Print files | All single watertight solids |
| Loads and spring sizing (`cad/tools/loads.py`) | Shoulder ≤ 5.4 kg·cm with the spring; elbow 9.2 kg·cm; spring 2.1 N/mm, 37 mm travel |
| Firmware | 28 offline tests pass |

**Not yet verified, because no physical build has happened:**
- real servo dimensions and horn hole patterns (the CAD uses datasheet values)
- print-service tolerances on press fits (bearings, splines, inserts)
- spring tuning, harness routing and the thermal printer's exact size

Expect some sanding, drilling to fit your horns, and a reprint or two. That's normal for a
first build.

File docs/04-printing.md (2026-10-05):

# 4. Printing

Every printable part is in `cad/stl/`. Regenerate the files with
`cd cad && ./tools/export.sh` after editing the model.

## Part list

The authoritative list is **`build/print_order_jlc3dp.csv`**: 27 numbered files in
`build/print_files/`, each with process, colour, size, volume and notes. Regenerate both
with `python3 cad/tools/package_build.py` after `cad/tools/export.sh`.

| Process | Parts |
|---|---|
| MJF PA12 nylon (or PETG at home, 40–60% infill) | housing, back plate, yaw tower, turret + mast, link1, link2, tilt post, covers, yaw coupler, spring block |
| SLA resin (strongly preferred for gears and splines) | head top (with ears), head middle, head chin, slot plate, eye carriage, eyelids, 18 T / 36 T pinions, rod bars, pulleys |
| Clear resin (tinted) | lens dome |
| TPU | neck bellows, chin bumper |

**Head mass:** about 696 g with 2.4 mm walls, CG about 1 mm from the tilt axis.

## Fasteners and hardware

| Item | Qty | Where |
|---|---|---|
| 608 bearing + 8 mm × 80 mm steel rod | 2 + 1 | yaw tower; shaft clamped by the turret and the coupler |
| 624 bearing + M4 × 20 shoulder bolt + nyloc | 3 | turret, elbow bracket, tilt post pivots |
| 3 mm steel rod, 148 mm | 2 | eye carriage guides |
| Extension spring (~2.1 N/mm, ~55 mm, OD ≤ 13 mm), 1 mm braided cable + 2 crimps, M3 axles + anchor pin + tensioner | 1 set | spring mast (2:1 reeving; pulleys are printed or bought) |
| M3 screws + heat-set inserts | ~30 inserts | covers (4), head seams (8), rod bars (6), back plate (4), coupler (1), spares |
| Servo horn screws | 4 per servo | horns → side plates and + ear |
| #8 × 2 in wood screws | 2 | back plate keyholes into the stud |
| Split-loom tubing 6–8 mm, zip ties | ~1 m | service tubes, harness |

## Cosmetic finishing

- **Lettering and seals:** engraved 0.6 mm. Fill with black paint and wipe, or print
  multi-colour.
- **Dymo labels:** real embossed Dymo tape on the head's right side.
- **Hex screws:** M3 button-head hex bolts at the marked seam spots.
- **Paper strip:** a real 58 mm strip printed on the thermal printer and glued into the chin slot.

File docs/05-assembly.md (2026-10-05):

# 5. Assembly

Build in this order so each stage gets tested before it's buried. Do the checks in
[Bring-up](07-bringup.md) at the steps marked ⚡.

Arm detail

## 0. Before you print

1. Measure your MG996R, DS3225, DS3218 and SG90s (body, flange, shaft offset, holes). Edit
   `MG`, `DS` and `SG` in `cad/voss.scad`.
2. Measure the printer module and speaker; edit `electronics()` and the housing.
3. Run `./tools/export.sh` and `python3 tools/collide.py`. Print only after `ALL CLEAR`.

## 1. Electronics on the bench ⚡

1. Flash Raspberry Pi OS Lite (Bookworm, 64-bit) and run `deploy/install.sh`.
2. Wire everything on a breadboard as in [Hardware → Wiring](02-hardware.md#wiring).
3. Test mics, amp, LEDs, printer and all six servo channels with `voss.calibrate`.

## 2. Housing

1. Press heat-set inserts into the back-plate edges and standoffs. Mount the Pi and PCA9685.
2. Fit:
   - the speaker behind the left grille
   - the mics behind their holes
   - the amp beside the speaker
3. Fit the printer exit-down over the slot in the bottom face.
4. Fit the DC jacks in the right side, and the 1000 µF capacitor across the PCA9685 V+/GND.
5. Fasten the yaw tower to the front with 4 × M3. Route the harness through the 12 mm hole.

## 3. Yaw

1. Press a 608 into each tower shelf.
2. Mount the MG996R shaft up, body toward the wall. ⚡ Run `calibrate zero` (yaw 90).
3. Screw the printed coupler to the MG996R horn and fit the horn. Push the 8 × 80 mm shaft
   down through both bearings into the coupler and tighten its M3 set screw. Fit the turret
   on top facing straight out and clamp it with its M3 screw.

## 4. Shoulder and counterbalance

1. Mount a DS3225 in the turret, shaft +Y, body down. Press a 624 into the pivot plate.
2. ⚡ Zero it. Fit link1 level: horn-side plate on the horn, other plate on the M4 bolt.
3. **Support the arm whenever the servos are unpowered until the spring is in.**
4. Hook the spring to the tensioner screw at the bottom of the mast bore, and hook the
   spring block (with its 7 mm pulley on an M3 axle) to the top of the spring.
5. Fit the 10 mm pulley on its M3 axle at the top of the mast.
6. **Reeve 2:1:** cable eye on link1 → over the top pulley → down under the spring-block
   pulley → up to the M3 anchor pin. Crimp it with the arm at 75° and the spring just taut.
7. ⚡ Tune with `calibrate float` (see [Bring-up](07-bringup.md#tuning-the-spring)).

## 5. Elbow and tilt post

1. Mount a DS3225 in link1's elbow bracket, body lying back along the beam. Press in a 624.
2. ⚡ Zero it. Fit link2 with the links in line.
3. Bolt the tilt post under link2's end block. Mount the DS3218 body up, press in a 624, and ⚡ zero it.

## 6. Eye

1. Fit the LED ring (LEDs forward) and the lens dome into the carriage.
2. Mount the eyelid SG90. ⚡ Run `set shutter 1`, then press its pinion on with both lids open.
3. Slide the lid tongues into the left rail groove and mesh the racks.
   ⚡ Run `set shutter 0` and back, then `shutter <closed> <open>`, until you get a 12 mm slit.
4. Push the two 3 mm rods through the carriage bushings and into the top and bottom mount bars.
5. Mount the lift SG90 on its strut. ⚡ Run `set eye 0`, then press the 36 T pinion onto the
   carriage rack with the eye centred.
6. ⚡ Run `set eye 1` and `set eye -1`. The eye should glide the full slot with no binding.

## 7. Head

1. Fit the status-bar LEDs behind the three windows and chain them after the eye ring.
2. Slide the eye assembly into the middle shell and fix the two rod bars with 6 × M3
   through the side walls into the bar-end inserts. Glue the slot plate behind the recess.
3. Press M3 inserts into the seam bosses of the top and middle pieces. Join the pieces with
   8 × M3 × 16, screwed up from inside the lower piece.
4. The ears are part of the crown print. Through the open back, bolt the + ear to the
   DS3218 horn, and pass the M4 pivot through the − ear into the 624.
5. Fit the TPU neck boot, the bumper, and a printed paper strip in the chin slot.

## 8. Harness and covers

1. Bundle the elbow, tilt, eyelid and eye-lift leads plus the LED line, then route them:
   - housing → corrugated loop → turret
   - top of link1 → loop over the elbow → top of link2
   - two neck tubes → open back of the head
2. Leave about 30 mm of slack at every loop. Run the arm through its range with
   `calibrate demo` and watch for snags.
3. Zip-tie the bundle to the beam tops and snap the covers on (2 × M3 each).

## 9. Wall

1. Find a stud. Drive two #8 screws 150 mm apart vertically, heads 4 mm proud.
2. Hang the back plate on the keyholes, slide the housing on, and fix the four side screws.
3. Check the reach envelope: the head swings up to about 430 mm out and about 255 mm to
   each side (see [Software → Reach](06-software.md#reach)).
4. ⚡ Run the full bring-up, then `sudo systemctl start voss`.

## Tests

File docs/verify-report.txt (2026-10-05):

BOLT PATHS (probe cylinder must pass through both parts without touching material)
  OK  tower->housing M3 (-24,-66)                  housing:0.0  tower:0.0
  OK  tower->housing M3 (-24,18)                   housing:0.0  tower:0.0
  OK  tower->housing M3 (24,-66)                   housing:0.0  tower:0.0
  OK  tower->housing M3 (24,18)                    housing:0.0  tower:0.0
  OK  harness hole housing/tower                   housing:0.0  tower:0.0
  OK  housing->back plate M3 (-1,10)               housing:0.0  back_plate:0.0
  OK  housing->back plate M3 (-1,-160)             housing:0.0  back_plate:0.0
  OK  housing->back plate M3 (1,10)                housing:0.0  back_plate:0.0
  OK  housing->back plate M3 (1,-160)              housing:0.0  back_plate:0.0
  OK  post->link2 M3 x=104                         link2:0.0  post:0.0
  OK  post->link2 M3 x=124                         link2:0.0  post:0.0
  OK  cover1->link1 M3 x=52                        link1:0.0  cover1:0.0
  OK  cover1->link1 M3 x=68                        link1:0.0  cover1:0.0
  OK  cover2->link2 M3 x=52                        link2:0.0  cover2:0.0
  OK  cover2->link2 M3 x=90                        link2:0.0  cover2:0.0
  OK  head wall->rod bar M3 (-3,-60,-45)           head_mid:0.0  eye_rods:0.0
  OK  head wall->rod bar M3 (-3,-60,-187)          head_mid:0.0  eye_rods:0.0
  OK  head wall->rod bar M3 (-27,-60,-187)         head_mid:0.0  eye_rods:0.0
  OK  head wall->rod bar M3 (-3,60,-45)            head_mid:0.0  eye_rods:0.0
  OK  head wall->rod bar M3 (-3,60,-187)           head_mid:0.0  eye_rods:0.0
  OK  head wall->rod bar M3 (-27,60,-187)          head_mid:0.0  eye_rods:0.0
  OK  seam top/mid M3 (-60,-63)                    head_top:0.0  head_mid:0.0
  OK  seam mid/chin M3 (-60,-59.5)                 head_mid:0.1  head_chin:0.0
  OK  seam top/mid M3 (-60,63)                     head_top:0.0  head_mid:0.0
  OK  seam mid/chin M3 (-60,59.5)                  head_mid:0.1  head_chin:0.0
  OK  seam top/mid M3 (32,-63)                     head_top:0.0  head_mid:0.0
  OK  seam mid/chin M3 (32,-59.5)                  head_mid:0.1  head_chin:0.0
  OK  seam top/mid M3 (32,63)                      head_top:0.0  head_mid:0.0
  OK  seam mid/chin M3 (32,59.5)                   head_mid:0.1  head_chin:0.0

PRINT FILES (watertight, single body)
  OK  housing           144.0 x   70.0 x  226.0 mm   228.6 cm3  bodies=1
  OK  back_plate        137.4 x    9.0 x  219.4 mm   119.6 cm3  bodies=1
  OK  tower              60.0 x   61.0 x  102.0 mm    56.7 cm3  bodies=1
  OK  turret             44.0 x   73.0 x  155.0 mm    58.4 cm3  bodies=1
  OK  link1             158.0 x   75.8 x   32.0 mm    57.4 cm3  bodies=1
  OK  link2             146.0 x   62.2 x   32.0 mm    54.8 cm3  bodies=1
  OK  post               32.0 x   45.8 x   82.0 mm    18.6 cm3  bodies=1
  OK  cover1             25.3 x   30.0 x   20.0 mm     2.6 cm3  bodies=1
  OK  cover2             47.3 x   30.0 x   20.0 mm     5.1 cm3  bodies=1
  OK  p_head_top        150.0 x  140.0 x   75.0 mm   129.6 cm3  bodies=1
  OK  p_head_mid        143.3 x  136.8 x  160.0 mm   190.0 cm3  bodies=1
  OK  p_head_chin       128.4 x  129.6 x   75.0 mm   109.5 cm3  bodies=1
  OK  p_eye_plate         2.0 x   92.0 x  148.0 mm    13.4 cm3  bodies=1
  OK  p_rod_bar_top      10.0 x  131.3 x    6.0 mm     7.6 cm3  bodies=1
  OK  p_rod_bar_bottom   42.0 x  124.8 x   86.0 mm    28.9 cm3  bodies=1
  OK  p_carriage         30.6 x  111.5 x  166.0 mm    73.3 cm3  bodies=1
  OK  p_lens              8.0 x   60.0 x   60.0 mm    11.5 cm3  bodies=1
  OK  p_lid_top           5.8 x   86.6 x   80.0 mm     7.8 cm3  bodies=1
  OK  p_lid_bottom        5.8 x  106.1 x   86.0 mm     8.6 cm3  bodies=1
  OK  p_pinion18          3.2 x   20.0 x   19.8 mm     0.7 cm3  bodies=1
  OK  p_pinion36         38.0 x    4.0 x   38.0 mm     3.9 cm3  bodies=1
  OK  p_yaw_coupler      24.0 x   24.0 x   11.0 mm     2.8 cm3  bodies=1
  OK  p_pulley           10.4 x   10.4 x    5.0 mm     0.4 cm3  bodies=1
  OK  p_pulley_small      7.4 x    7.4 x    4.8 mm     0.2 cm3  bodies=1
  OK  p_spring_block     12.0 x   10.0 x   16.0 mm     1.0 cm3  bodies=1
  OK  p_neck_boot        54.0 x   58.3 x   28.7 mm    10.0 cm3  bodies=1
  OK  p_bumper           22.0 x   22.0 x    8.5 mm     3.2 cm3  bodies=1

ALL CHECKS PASSED

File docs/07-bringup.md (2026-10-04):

# 7. Bring-up and calibration

## Install

On a fresh Raspberry Pi OS Lite (Bookworm, 64-bit):

```bash
git clone <this repo> voss && cd voss
sudo ./deploy/install.sh        # packages, venv, models, systemd unit, config.txt lines
sudo nano /etc/voss.env         # ANTHROPIC_API_KEY, VOSS_LAT, VOSS_LON
sudo reboot
```

The installer:
- appends `deploy/config.txt.snippet` to `/boot/firmware/config.txt` (I2C, SPI, UART,
  voicehat overlay, fixed core clock)
- frees the serial port from the login console
- downloads Piper, the amy-low voice, the Vosk small model and the openWakeWord models

## First power-on, in order

All commands run from `/opt/voss` as `sudo -u voss venv/bin/python -m voss.calibrate …`.

| Step | Command | Pass when |
|---|---|---|
| 1. Audio card | `arecord -l` | `sndrpigooglevoi` is listed |
| 2. Mics | `arecord -D plughw:CARD=sndrpigooglevoi -c 2 -r 16000 -f S16_LE -d 3 t.wav && aplay t.wav` | You hear yourself |
| 3. LEDs | `leds` | Red, green, blue and amber wipe across all 19 |
| 4. Servo zero | `zero` | Yaw 90, link1 level, links in line, head level, eye centred. Fit horns now; support the arm before releasing |
| 5. Trim | `trim shoulder -3` (yaw, shoulder, elbow, tilt) | Link1 level and links straight at zero |
| 6. Spring | `float` | See below |
| 7. Range | `set shoulder 60`, `set shoulder -20`, `set elbow -60` | Moves smoothly; head stays level |
| 8. Eyelids | `set shutter 0`, `set shutter 1`, `shutter 4 176` | 12 mm slit closed; lids hidden when open |
| 9. Eye lift | `set eye 1`, `set eye -1`, `set eye 0` | Eye glides the full slot, centred at 0 |
| 10. Direction | `doa` | Clap on the left → negative, right → positive |
| 11. Printer | `print` | Test memo drops out of the bottom |
| 12. Show | `demo` | All five moods play |
| 13. Service | `sudo systemctl start voss && journalctl -u voss -f` | "V.O.S.S. online" |

## Tuning the spring

`calibrate float` raises the arm to 30°, then releases only the shoulder servo.

| What the arm does | Fix |
|---|---|
| Floats up and settles near 50° | Tuned |
| Sinks | Tighten the tensioner screw at the bottom of the mast |
| Shoots up hard | Loosen it |
| Still sinks with the screw nearly maxed | The spring is too weak: use a stiffer one, or shorten the cable one crimp |

A well-tuned arm stays roughly wherever you push it, like a desk lamp.

## Troubleshooting

| Symptom | Fix |
|---|---|
| Capture glitches or silence | `VOSS_CAPTURE_RATE=48000` |
| Very quiet speech | Raise `VOSS_MIC_GAIN` (6–8) |
| Arm turns the wrong way to talkers | Swap the mics' L/R strap pins, or flip the sign in `audio.doa_degrees` |
| LEDs flicker or show wrong colours | Add a 74AHCT125 level shifter; check the `core_freq` lines |
| Printer prints garbage | Check `VOSS_PRINTER_BAUD`, and that the serial console is off |
| Pi reboots when the arm moves | Servos must be on the separate 6 V rail with a common ground |
| Shoulder hums or gets warm | The spring needs tightening (`float`) |
| Eye drifts down at rest | Lift pinion slipping on the spline: tighten its screw, or reprint it with a tighter bore |
| Eye binds in the slot | Rods not parallel: loosen the mount bars, run `set eye 1` / `-1`, retighten |
| False wake-ups | Raise `VOSS_WAKE_THRESHOLD`; train "hey voss" |

## Training "hey voss"

Use openWakeWord's synthetic-data training notebook to make `hey_voss.onnx`. Copy it to
`/opt/voss/models/` and set `VOSS_WAKE_MODEL=/opt/voss/models/hey_voss.onnx`.

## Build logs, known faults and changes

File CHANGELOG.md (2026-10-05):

# Changelog

## v0.7 — build-verified (2026-10)

A full audit for real-world buildability, plus the build package.

**Fixes**
- **Gears:** real involute module-1 pinions (18 T, 36 T) and matching racks, phased to engage.
  The mesh check proves engagement with no interference.
- **Pinion bores:** 21 T SG90 spline bore plus the M2 horn screw (round bores would spin).
- **Spring mast:**
  - A single coplanar pulley directly above the shoulder (the old route bent between
    non-coplanar pulleys and had no axles).
  - The arm and yaw tower are raised 70 mm (`ARM_Z0`) so the mast clears the housing at
    every yaw.
  - 2:1 reeving so the spring travels 37 mm instead of an impossible ~210% stretch.
- **Fastening:**
  - Head seam screws (insert bosses plus clearance bosses).
  - Ears printed with the crown.
  - Rod bars extended to the walls, with insert holes and matching wall holes.
  - Cover screw pads in the beams.
  - Lens holder fused to the carriage, with a seat lip.
  - One-piece bellows.
  - Rod mounts exported as their two real parts.
- **New parts:** yaw coupler, 10 mm and 7 mm pulleys, spring block. The yaw shaft is now
  8 × 80 mm.
- Cosmetic-only geometry (screw heads, inlays) is excluded from print files.

**New tools and outputs**
- `verify.py`: bolt-path and print-solid checks.
- `package_build.py` builds `build/`: 27 print files, the JLC3DP order sheet, `BOM.csv`
  and `BUILD.md`.
- GitHub CI, license note and templates.
- 24 fps animation.

## v0.6 — expression engine (2026-10)

**Motion engine**
- Rebuilt as a queue of timed segments with easing styles (`ease`, `spring`, `snap`,
  `slow`, `hold`). There are no gesture threads any more. Tests and the animation tool
  drive it on a virtual clock.

**Gestures**
- New `voss/gestures.py` with 13 data-defined gestures: nod, bounce_nod, shake, peer,
  double_take, startle, sigh, scan, curious, stamp, glance_back, flutter, ack.
- Uses anticipation, overshoot-and-settle, holds, and eye/lid secondary motion.

**Claude control**
- Replies can carry an optional gesture tag after the mood. The persona prompt lists them,
  and `persona.parse_tags()` parses them.

**Moods**
- Each mood has an entry pose, a signature gesture and an idle profile (sway amplitude and
  speed, blink rate).

**Secondary motion**
- Natural blinks with doubles, speech-onset emphasis nods, and eye-led looks.

**Tooling and docs**
- New `calibrate gesture <name>`.
- New 36 s animation (`docs/img/voss_expressive.mp4/.gif`) rendered from the CAD with the
  real motion engine.
- 28 tests, all passing.

## v0.5 — V.O.S.S. (2026-10)

**Rename**
- M.E.M.O. → **V.O.S.S.** (Virtual Oversight & Supervision System) everywhere: package
  `voss`, service `voss`, `VOSS_*` settings, persona, lettering, printed memos.
- New personnel-record bio (`docs/00-bio.md`).

**Arm**
- Desk-lamp counterbalance: a gooseneck spring mast on the turret, with the cable eye on
  link1's axis line. The shoulder load drops from ~20 to ≤5.4 kg·cm, and the arm floats
  at ~51° unpowered.
- Shoulder and elbow servos are now DS3225; the servo supply drops to 6 V 6 A.
- Top-only arm covers with the wire harness underneath. Corrugated service tubes at the
  base, over the elbow, and into the head.

**Head**
- Deeper head: 151 mm at the crown, 125 mm lower down, chin tapered. It's shifted 15 mm on
  the tilt axis so its CG hangs under the axis.
- Open upper back, widened behind the ears. Tilt range grows from −35…+40° to **−40…+50°**.
- **Moving eye:** lens, LED ring and eyelids ride a carriage ±24 mm up and down the slot
  on two 3 mm rods. A second SG90 drives it with a 36 T rack and pinion. A sliding mask
  hides the open lids at any height.
- Original "Personnel Compliance • Branch 04" department seal on the housing and the head's
  left side.

**Housing**
- Printer mounted exit-down (memos drop out of the bottom); the yaw tower blocked the old
  front slot.
- Speaker moved to the left; jacks and vents moved to the sides; lettering moved to the bottom.

**Firmware**
- New `eye` joint (channel 5) and mood-specific eye heights.
- GLaDOS-style motion: minimum-jerk easing, idle sway, eye saccades, a speech-driven head
  bob, overshoot-and-settle looks, and the loom-and-drop stamp.
- Workspace check models the tapered head as four depth sections that swing with pitch.
- Rest and park at the spring's balance point. New `calibrate float` for spring tuning.

**CAD tools**
- New `loads.py`, `head_mass.py` and `reach.py`.
- The collision sweep now covers the moving eye (3 heights × 3 lid positions) and the new
  tilt range: all clear.

## v0.4 — classic arm (2026-10, as M.E.M.O.)

**Arm**
- Replaced the fold-flat horizontal-plane arm with a classic one: base yaw, then shoulder,
  elbow and head-tilt pitch.
- New yaw tower: an 8 mm shaft in two 608 bearings, driven by an MG996R.
- Shoulder and elbow brackets reuse the tilt-post joint bracket, with 624 bearings opposite
  each servo.
- Links are side plates around each bracket feeding a hollow centre beam.

**Servos and power**
- 35 kg·cm shoulder, DS3218 elbow, DS3218 tilt, MG996R yaw.
- Servo supply raised to 6 V 10 A.
- PCA9685 now uses channels 0–4.

**Firmware**
- Pose model is now yaw / shoulder / elbow / absolute head pitch; the tilt servo is derived,
  so the head stays level.
- New workspace check: the head is a plan-view capsule that follows its pitch swing, checked
  against the housing, the yaw tower and the wall.
- The shoulder and elbow always hold. Rest folds the arm upright and releases only yaw, tilt
  and shutters. Shutdown lowers the arm before cutting power.
- The stamp is now a real ~50 mm drop.

**CAD and docs**
- Collision checker rewritten for the new joints and run against a 4-D firmware pose grid:
  all clear.
- Docs and renders updated.

## v0.3 — rebuild (2026-10, as M.E.M.O.)

The v0.2 project files were unavailable, so everything was rebuilt from the written spec.

**Hardware**
- Bigger head: ~300 × 140 × 90 mm (was a 76 mm pod).
- Servos: MG996R shoulder and elbow, DS3218 tilt (were 3× MG90S), plus a new SG90 driving
  the eye shutters.
- Separate 6 V servo supply. PCA9685 OE on GPIO17 cuts servos at rest and while printing.
- 19 LEDs: a 16-LED eye ring plus REC, AUD and OK status blocks.

**Geometry**
- Shoulder axis moved to y = 108 and housing deepened to 70 mm, to fit the MG996R
  bracket and the printer.
- Head hangs as a pendulum from a tilt axis near its top, at z −184.

**Firmware**
- Workspace model changed to head centre 114 / radius 84.
- Shutter calibration defaults 4–176°.
- Shoulder and elbow speeds reduced for the heavier head.

**New**
- Full parametric OpenSCAD model, STLs, renders and a mesh-based collision checker.
- This documentation.

## v0.2

Original software and MG90S CAD (not included in this repository).

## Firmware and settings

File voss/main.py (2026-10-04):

"""V.O.S.S. main loop.

  python -m voss.main            voice mode (wake word -> STT -> Claude -> TTS)
  python -m voss.main --text     type to her instead (good for desktop testing with VOSS_SIM=1)
"""
import argparse
import logging
import queue
import signal
import threading
import time

from . import config
from .audio import Capture, Player, doa_degrees
from .body import Body
from .brain import Brain
from .lights import Lights
from .printer import Printer
from .tools import ToolBox

log = logging.getLogger("voss")


class Voss:
    def __init__(self, voice=True):
        self.events = queue.Queue()
        self.body = Body()
        self.lights = Lights()
        try:
            self.printer = Printer(self.body)
        except Exception:
            log.exception("printer unavailable")
            self.printer = None
        self.toolbox = ToolBox(self.events, self.printer)
        self.brain = Brain(self.toolbox)
        self.player = Player()
        self.voice = None
        if voice:
            try:
                from .tts import Voice
                self.voice = Voice()
            except Exception as e:
                log.warning("TTS unavailable (%s); replies will be text only", e)
        self.last_activity = time.monotonic()
        self.rested = False
        self._filed = False

    # ------------------------------------------------------------ lifecycle
    def start(self):
        self.body.start()
        self.lights.start()
        self.body.home()
        self.lights.set_mode("idle", "neutral")

    def stop(self):
        self.lights.stop()
        self.body.stop()

    # ------------------------------------------------------------ output
    def _on_tool(self, name, args):
        self.lights.pulse_aud(1.0)
        if name == "notes" and (args or {}).get("action") == "add":
            self.body.filing()
            self._filed = True

    def _on_level(self, level):
        self.lights.set_level(level)
        self.body.speech(level)

    def speak(self, mood, text, gesture=None):
        print(f"V.O.S.S. [{mood}]" + (f"[{gesture}]" if gesture else "") + f": {text}", flush=True)
        self.body.mood(mood, gesture)
        self.lights.set_mode("speak", mood)
        sfx = (["click"] if self._filed else []) + (["thunk"] if mood == "infraction" else [])
        self._filed = False
        try:
            if self.voice:
                wav = self.voice.render(text, chime=True, sfx=sfx)
                self.player.play(wav, on_level=self._on_level)
        except Exception:
            log.exception("speech failed")
        finally:
            self.lights.set_mode("idle", mood if mood == "concern" else "neutral")
            if mood == "sulk":
                threading.Timer(6.0, lambda: self.events.put(("unsulk", None))).start()
            elif mood != "concern":
                self.body.home()
            self.last_activity = time.monotonic()
            self.rested = False

    def respond(self, text):
        self.body.set_awake(True)
        self.lights.set_mode("think")
        self.body.think()
        mood, gesture, reply, _ = self.brain.ask(text, on_tool=self._on_tool)
        self.speak(mood, reply, gesture)

    def handle_events(self):
        while True:
            try:
                kind, data = self.events.get_nowait()
            except queue.Empty:
                break
            if kind == "timer":
                self.speak("neutral", f"Attention, Employee. Your {data} timer has concluded. "
                                      "Please proceed to the next scheduled activity.")
            elif kind == "unsulk":
                self.body.home(0.4)
        if not self.rested and time.monotonic() - self.last_activity > config.REST_AFTER_S:
            self.body.rest()
            self.lights.set_mode("idle", "neutral")
            self.rested = True

    # ------------------------------------------------------------ voice loop
    def run_voice(self):
        from .stt import Listener, WakeWord
        wake, listener = WakeWord(), Listener()
        cap = Capture()
        cap.start()
        log.info("V.O.S.S. online. Wake word: %s", config.WAKE_MODEL)
        while not self._stopping:
            self.handle_events()
            chunk = cap.get(timeout=0.3)
            if chunk is None or not wake.detect(chunk):
                continue
            angle = doa_degrees(cap.recent(1.0))
            log.info("talker at %s deg", "?" if angle is None else f"{angle:.0f}")
            self.body.set_awake(True)
            if angle is not None:
                self.body.look(angle)
            else:
                self.body.listen()
            self.lights.set_mode("listen", "neutral")
            if self.voice:
                self.player.play(self.voice.sound("chime"))
            cap.flush()
            text = listener.listen(cap)
            if text:
                self.respond(text)
            else:
                self.lights.set_mode("idle", "neutral")
                self.body.home()
            cap.flush()
            wake.reset()
            self.last_activity = time.monotonic()
        cap.stop()

    def run_text(self):
        stop = threading.Event()

        def ticker():
            while not stop.is_set():
                self.handle_events()
                time.sleep(0.2)
        threading.Thread(target=ticker, daemon=True).start()
        print("Type to V.O.S.S. (Ctrl-D to quit).")
        try:
            while True:
                line = input("Employee: ").strip()
                if line:
                    self.respond(line)
        except (EOFError, KeyboardInterrupt):
            pass
        stop.set()

    _stopping = False


def main():
    ap = argparse.ArgumentParser()
    ap.add_argument("--text", action="store_true", help="keyboard input instead of microphones")
    ap.add_argument("--mute", action="store_true", help="no TTS output")
    ap.add_argument("-v", "--verbose", action="store_true")
    args = ap.parse_args()
    logging.basicConfig(level=logging.DEBUG if args.verbose else logging.INFO,
                        format="%(asctime)s %(name)s %(levelname)s %(message)s")
    voss = Voss(voice=not args.mute)

    def _term(*_):
        voss._stopping = True
        raise SystemExit(0)
    signal.signal(signal.SIGTERM, _term)
    voss.start()
    try:
        voss.run_text() if args.text else voss.run_voice()
    finally:
        voss.stop()


if __name__ == "__main__":
    main()

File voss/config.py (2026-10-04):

"""V.O.S.S. configuration.

Every value can be overridden with an environment variable. On the Pi, put
overrides in /etc/voss.env (loaded by the systemd unit).

Frame: X along the wall, Y out of the wall, Z up. Wall face is y = 0.
"""
import os
from pathlib import Path


def _get(name, default, cast=str):
    raw = os.environ.get(name)
    if raw is None or raw.strip() == "":
        return default
    if cast is bool:
        return raw.strip().lower() in ("1", "true", "yes", "on")
    return cast(raw)


def _opt_float(name):
    raw = os.environ.get(name)
    return float(raw) if raw not in (None, "") else None


# ---------------------------------------------------------------- paths / mode
ROOT = Path(_get("VOSS_ROOT", "/opt/voss"))
DATA_DIR = Path(_get("VOSS_DATA", str(ROOT / "data")))
MODELS_DIR = Path(_get("VOSS_MODELS", str(ROOT / "models")))
SIM = _get("VOSS_SIM", False, bool)          # no hardware: fake servos/LEDs/printer

# ---------------------------------------------------------------- Claude
MODEL = _get("VOSS_MODEL", "claude-haiku-4-5-20251001")
MAX_TOKENS = _get("VOSS_MAX_TOKENS", 300, int)
HISTORY_TURNS = _get("VOSS_HISTORY_TURNS", 8, int)   # user+assistant exchanges kept
MAX_TOOL_ROUNDS = 5
API_TIMEOUT_S = 20.0

# ---------------------------------------------------------------- audio
ALSA_CAPTURE = _get("VOSS_ALSA_CAPTURE", "plughw:CARD=sndrpigooglevoi,DEV=0")
ALSA_PLAYBACK = _get("VOSS_ALSA_PLAYBACK", "plughw:CARD=sndrpigooglevoi,DEV=0")
CAPTURE_RATE = _get("VOSS_CAPTURE_RATE", 16000, int)   # 16000, or 48000 fallback
RATE = 16000                                           # pipeline rate
CHUNK = 1280                                           # 80 ms (openWakeWord frame)
MIC_GAIN = _get("VOSS_MIC_GAIN", 4.0, float)           # INMP441s are quiet
MIC_SPACING_M = 0.080
SPEED_OF_SOUND = 343.0
DOA_MAX_DEG = 60.0
DOA_MIN_RMS = 200.0                                    # ignore DOA below this level

# ---------------------------------------------------------------- wake word
WAKE_MODEL = _get("VOSS_WAKE_MODEL", "hey_jarvis")     # built-in name or path to .onnx
WAKE_THRESHOLD = _get("VOSS_WAKE_THRESHOLD", 0.5, float)
WAKE_COOLDOWN_S = 1.5

# ---------------------------------------------------------------- speech to text
VOSK_MODEL = Path(_get("VOSS_VOSK_MODEL", str(MODELS_DIR / "vosk-model-small-en-us-0.15")))
VAD_AGGRESSIVENESS = 2
SILENCE_END_MS = 700
MAX_UTTERANCE_S = 8.0
NO_SPEECH_TIMEOUT_S = 4.0

# ---------------------------------------------------------------- text to speech
PIPER_BIN = _get("VOSS_PIPER_BIN", "piper")
PIPER_MODEL = Path(_get("VOSS_PIPER_MODEL", str(MODELS_DIR / "en_US-amy-low.onnx")))
INTERCOM_FX = _get("VOSS_INTERCOM", True, bool)

# ---------------------------------------------------------------- servos
I2C_BUS = 1
PCA9685_ADDR = 0x40
SERVO_FREQ = 50
SERVO_OE_GPIO = _get("VOSS_SERVO_OE_GPIO", 17, int)   # PCA9685 OE; -1 = not wired.
                                                      # (GPIO16 is taken by the voicehat overlay)
CALIBRATION_FILE = DATA_DIR / "calibration.json"
REST_AFTER_S = 45.0          # idle time before the arm homes and yaw/tilt/shutter go limp

# Default calibration (6 channels). Yaw MG996R, shoulder + elbow DS3225 (the shoulder is
# spring-balanced), tilt DS3218, shutters SG90, eye lift SG90.  servo_deg = offset_deg +/- joint_deg.
DEFAULT_CALIBRATION = {
    "yaw":      {"ch": 0, "min_us": 500, "max_us": 2500, "range_deg": 180, "offset_deg": 0,   "invert": False},
    "shoulder": {"ch": 1, "min_us": 500, "max_us": 2500, "range_deg": 180, "offset_deg": 90,  "invert": False},
    "elbow":    {"ch": 2, "min_us": 500, "max_us": 2500, "range_deg": 180, "offset_deg": 130, "invert": False},
    "tilt":     {"ch": 3, "min_us": 500, "max_us": 2500, "range_deg": 180, "offset_deg": 90,  "invert": False},
    "shutter":  {"ch": 4, "min_us": 500, "max_us": 2400, "range_deg": 180, "closed_deg": 4, "open_deg": 176},
    "eye":      {"ch": 5, "min_us": 500, "max_us": 2400, "range_deg": 180, "low_deg": 14, "high_deg": 166},
}

# Joint conventions (match cad/assembly.scad):
#   yaw 90 = arm straight out from the wall;  shoulder 0 = link1 horizontal, + lifts;
#   elbow 0 = links in line, + lifts link2;  pitch = absolute head pitch, + nose down.
#   The tilt servo is derived: tilt = pitch + shoulder + elbow (keeps the head level).
LIMITS = {
    "yaw": (5.0, 175.0),
    "shoulder": (-20.0, 75.0),
    "elbow": (-110.0, 40.0),
    "pitch": (-40.0, 45.0),
    "tilt": (-40.0, 50.0),      # servo range, CAD collision-checked (open-back deep head)
    "shutter": (0.0, 1.0),
    "eye": (-1.0, 1.0),         # eye height in the slot, +-24 mm
}
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

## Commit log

2026-10-04 M.E.M.O. v0.3: rebuilt firmware, full parametric CAD, collision checks, docs
    [assembly.scad, back_plate.stl, bezel.stl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]
2026-10-04 v0.4: classic yaw/shoulder/elbow arm, derived head tilt, capsule workspace check, docs
    [assembly.scad, back_plate.stl, bracket.stl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]
2026-10-04 v0.5: V.O.S.S. rename, desk-lamp spring, deep open-back head, moving eye, covers + harness, docs
    [assembly.scad, back_plate.stl, bezel.stl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]
2026-10-04 Animated routine (GIF/MP4) rendered from CAD + firmware poses
2026-10-05 v0.7: build audit fixes (involute gears, coplanar 2:1 spring mast, fastening), verify + build package, GitHub files
    [01_housing.stl, 02_back_plate.stl, 03_yaw_tower.stl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]
2026-10-05 24 fps 15 s animation; FAST render mode for animation
    [voss.scad]
